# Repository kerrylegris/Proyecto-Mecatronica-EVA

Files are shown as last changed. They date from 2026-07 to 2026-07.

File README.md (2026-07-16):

# Proyecto-Mecatronica 4250-EVA
evacad
EVAFinal

## Integrantes
* Agustín Ketterer
* Isabella Silva
* Katalyna Tapia
* Joaquín Zúñiga
## Profesor
* Harold Valenzuela
## Auxiliar
* Fernando Navarrete
## Ayudantes
* Valentina Abarca
* Emilia Gutiérrez
# Índice de contenidos
* [Descripción](#descripción)
* [Objetivos](#objetivos)
* [Listado de materiales](#listado-de-materiales)
* [Diseño](#diseño)
* [Electrónica](#electrónica)
* [Software y lógica](#software-y-lógica)
* [Archivos CAD](./EVA%20CADs/)
* [Multimedia](./Multimedia)
  
# Descripción
El presente repositorio contiene la documentación, códigos y modelos 3D correspondientes al desarrollo del Robot Autobalancín "EVA".

El prototipo consiste en un péndulo invertido sobre dos ruedas capaz de mantener su verticalidad de forma autónoma frente a perturbaciones. A diferencia de los modelos clásicos, este proyecto destaca por incorporar un diseño estético basado en el personaje EVA de la película WALL-E, que responde a la solicitud de aplicar una estética futurista a nuestra propuesta, modelado íntegramente en Fusion 360. Para compatibilizar esta geometría con las exigencias dinámicas del equilibrio, se desarrolló una arquitectura interna estructurada en niveles que optimiza el centro de masa y permite un enrutamiento limpio del hardware.

A nivel de sistema, el robot es contorlado por una placa Arduino Uno, la cual procesa en tiempo real los datos de inclinación y aceleración capturados por un sensor inercial MPU-6050. Mediante la ejecución de un algoritmo de control PID ajustado experimentalmente, el microcontrolador gestiona la respuesta de los actuadores (motores DC), demostrando la aplicación práctica de principios de dinámica de cuerpos rígidos y sistemas de control en lazo cerrado.

Características principales:

* Modelado CAD: Diseño en Fusion 360 de la carcasa externa y el chasis interno por niveles.

* Fabricación: Combinación de impresión 3D (PLA) para la estética y corte láser (acrílico) para el chasis estructural.

* Electrónica: Integración de Arduino Uno, sensor MPU-6050, drivers de potencia y motores reductores.

* Control: Sistema de auto-balanceo mediante algoritmo PID en C++.
# Objetivos 
El objetivo principal de este proyecto es el diseño mecatrónico y la construcción de un robot autobalancín funcional inspirado en la estética de EVA (WALL-E). Lo central del desafío consiste en implementar un controlador PID capaz de mantener el equilibrio dinámico del sistema, compensando la inercia generada por la masa superior de su estructura.

Para lograr este objetivo, se integrarán componentes electrónicos esenciales utilizando un microcontrolador Arduino UNO como unidad central de procesamiento. Este gestionará la lógica de control programada en C++ y la lectura continua de datos del sensor inercial MPU-6050 (encargado de medir los ángulos de inclinación) para comandar los actuadores (motores DC acoplados a las ruedas). Además, el proyecto incluye el diseño de una estética original y atractiva, estructurando el modelo CAD en niveles internos para lograr la geometría fluida del personaje sin comprometer la viabilidad mecánica del péndulo invertido.

Es importante definir que el alcance del proyecto se centra en la integración exitosa del hardware y en la demostración de un sistema de autobalanceo. Por lo tanto, aunque el prototipo físico deba lidiar con las complejidades de un centro de masa elevado debido a su diseño asimétrico, el objetivo principal radica en la aplicación práctica de la teoría de control para superar este reto.

# Listado de materiales
## Hardware
### Estructura
| Componente | Cant. | Material | Proceso | Archivo asociado |
| :--- | :---: | :---: | :---: | ---: |
| Cabeza EVA |1| PETG y PLA | Impresión 3D | Cabeza EVA, parte trasera y delantera |
| Carcasa EVA |1| PETG | Impresión 3D | Carcasas |
| Placas |3| Acrílico | Corte láser | Placa base, media y superior |
| Barras estructurales |8| PLA | Impresión 3D | Barras 40mm y 50mm|
| Ruedas |2| Plástico | - | - |
| Pernos | 8 | Acero comercial | - | |-|
### Componentes electrónicos
| Componente | Cant. | Uso | 
| :--- | :---: | ---: |
| Placa Arduino UNO R3|1| Unidad lógica |
| Sensor MPU-6050 |1 | Medición de ángulo | 
| Driver L298N | 2 | Controlador de los motores |
| Motor 6V | 2 | Actuadores para el movimiento del robot |
| Batería 3,7 V | 2 | Sistema de alimentación del sistema |
| Cables de conexión | 10 | Conexión de los componentes electrónicos |

# Diseño
## Inspiración
Para cumplir con el requerimiento del proyecto de implementar una estética futurista, el diseño exterior del robot toma como inspiración directa al personaje EVA (Extraterrestrial Vegetation Evaluator) de la película de animación WALL-E.

La justificación de esta elección geométrica y visual para representar el "futuro" se sostiene en los siguientes puntos:

Minimalismo de Alta Tecnología: La ciencia ficción y el diseño industrial moderno asocian el futurismo con la limpieza visual. EVA carece de uniones visibles, engranajes expuestos o bordes afilados. Su geometría está basada en curvas continuas, superficies lisas y un contraste marcado entre el blanco puro y la pantalla negra de su rostro, emulando la sofisticación de los dispositivos tecnológicos.

El Movimiento: El concepto original de EVA es el de una sonda que levita o flota suavemente. Aunque el prototipo mecatrónico utiliza ruedas, la dinámica misma de un robot autobalancín —que constantemente ajusta su centro de masa para mantenerse erguido sobre un solo eje— genera un movimiento fluido que imita conceptualmente la sensación de "flotabilidad" o anti-gravedad, alineándose a la perfección con la percepción de un vehículo futurista.

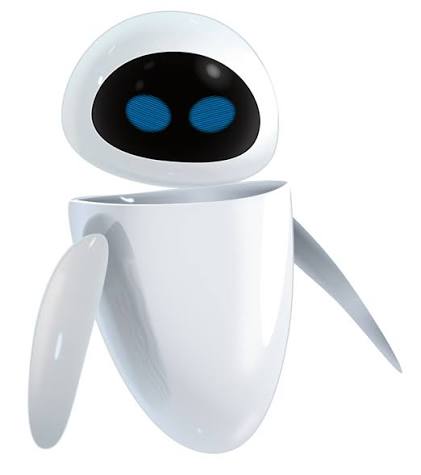
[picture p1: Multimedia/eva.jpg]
Inspiración: Personaje EVA


## Iteraciones
El desarrollo físico del robot fue un proceso iterativo, motivado por la necesidad de conciliar la compleja geometría de EVA con los estrictos requerimientos dinámicos y de distribución de masa de un péndulo invertido.
Iteración 1: Diseño preliminar con placa vertical
El enfoque: El primer diseño computacional en Fusion 360 buscó integrar la carcasa estética de EVA con una única placa vertical dispuesta en el interior, la cual serviría como soporte central para ensamblar todos los componentes electrónicos y mecánicos.
El problema: Al evaluar este ensamble preliminar, se evidenció que la placa vertical concentraba el peso de manera subóptima y limitaba severamente la flexibilidad para distribuir la masa. Además, dificultaba la accesibilidad para el cableado y el ajuste de los componentes, comprometiendo la viabilidad del balanceo.
##Diseño final 
Iteración 2: Transición al chasis horizontal por niveles
La solución: Se descartó la placa vertical en favor de un chasis interno estructurado en pisos horizontales (mediante placas de acrílico cortadas en láser y separadores cilíndricos).
El impacto: Esta nueva arquitectura permitió independizar el sistema estructural de la carcasa externa. Al tener niveles, se logró bajar drásticamente el centro de gravedad ubicando la batería y los motores en la base, lo cual fue fundamental para compensar la alta inercia generada por el apéndice superior impreso en 3D (la cabeza de EVA).

# Electrónica

El hardware de este robot autobalancín está compuesto por un microcontrolador central que procesa la información sensorial y comanda los actuadores en cuestión de milisegundos. La arquitectura electrónica se divide en los siguientes componentes principales:

*   **Microcontrolador (Arduino):** Ejecuta el lazo de control PID a alta velocidad y coordina la comunicación continua entre los sensores y el actuador.
*   **Módulo MPU6050 (Giroscopio y Acelerómetro):** Es el encargado de medir la inclinación física del cuerpo completo del robot en el espacio. Es el sensor principal que proporciona la retroalimentación del ángulo real.
*   **Driver de Motores L298N:** Actúa como puente de potencia; recibe las señales lógicas de dirección y los pulsos de velocidad (PWM) desde el microcontrolador, y las transforma en la corriente eléctrica necesaria para mover ambos motores.
*   **Motores DC:** Proporcionan el torque necesario para desplazar la base de la estructura e intentar devolver el centro de masa a su punto de equilibrio vertical.

**Distribución de Energía**
Debido a la alta demanda de corriente que exigen los motores al cambiar de dirección abruptamente para equilibrar la estructura, el circuito requiere una fuente de alimentación externa con buena capacidad de descarga, conectada directamente al módulo L298N. 

<!-- A continuación, se presenta el esquema detallado de las conexiones del sistema:y -->

# Software y lógica
El bloque de texto que contiene el código con el que se programó el PID se puede encontrar en su respectiva [carpeta](./Código). 

El propósito de este proyecto es lograr que el robot mantenga el equilibrio en dos ruedas de forma autónoma, pero debido a naturaleza inestable tenderá a caer hacia adelante o hacia atrás. Para contrarrestar la gravedad se utiliza un sistema de control de lazo cerrado que calcula constantemente su ángulo de inclinación y acelera sus ruedas en la misma dirección de la caída, empujando la base debajo del centro de masa para regresar a su punto de equilibrio (0 grados). La siguiente imagen corresponde al diagrama del sistema de control que muestra el flujo de las señales, más adelante se explica con mayor detalle la descripción de cada parte.

Diagrama eva (1)

El código está diseñado para operar en un ciclo de tiempo determinado (200 Hz o cada 5 milisegundos) y se divide en tres pilares fundamentales:

**1. Calibración y lectura sensorial**
Al encender, el sistema ejecuta una fase de calibración de 3 segundos. Durante este tiempo, promedia los valores en reposo del sensor MPU6050 para establecer un "cero" real, compensando cualquier error de fábrica. 
Durante el ciclo continuo, el sistema calcula el ángulo de inclinación actual  (`input_angle`), fusionando los datos del acelerómetro y el giroscopio mediante un filtro complementario. Este filtro se configura para un 98% en las lecturas del giroscopio y en un 2% en el acelerómetro, para corregir el error acumulado que sufre el giroscopio a largo plazo.

**2. Controlador PID**
El error entre el ángulo objetivo y el real alimenta la ecuación de control PID, que calcula la fuerza necesaria (`output_u`) para enderezar el robot:
*   **Proporcional (Kp):** La fuerza principal;  cuanto más se inclina el robot, más potencia exige.
*   **Integral (Ki):** Acumula errores pasados para corregir pequeñas desviaciones. Incluye un límite (*anti-windup*) para evitar que la memoria se sature si el sistema no logra estabilizarse inmediatamente.
*   **Derivador (Kd):** Reacciona a la velocidad de la caída; frena la potencia si el robot ya está regresando rápidamente a su centro, evitando que oscile de un lado a otro.

**3. Accionamiento de Motores y Seguridad**
El código compensa la fricción sumando un pulso mínimo (`MIN_PWM = 30`), asegurando que los motores reaccionen instantáneamente ante cualquier corrección, por muy pequeña que sea. 
Adicionalmente, se incluye un mecanismo de seguridad pasivo: si el ángulo supera los 60 grados de inclinación (`ANGULO_CORTE`), el sistema asume que la estructura ya cayó. Para evitar daños o movimientos erráticos por el suelo se corta la potencia y se reinicia la memoria del controlador.

A continuación se puede observar el diagrama de lógica que sigue la programación de EVA.
<details>
<summary>Ver Diagrama de lógica</summary>
  
```mermaid
graph TD
    %% Fase de Inicialización
    A([Inicio de Sistema]) --> B[Configurar Serial e I2C]
    B --> C[inicializarMOTORS]
    C --> D[inicializarSENSORS]
    D --> E{¿Pasaron 3 seg?}
    E -- No --> F[Leer y acumular datos MPU]
    F --> E
    E -- Sí --> G[Calcular offsets]
    G --> H[Guardar prev_time]

    %% Bucle Principal y Peaje de Tiempo
    H --> I([Inicio Loop])
    I --> J[Calcular dt]
    J --> K{¿dt >= 0.005s?}
    K -- No --> I
    K -- Sí --> L[leerSENSORS y calcular input_angle]
    
    %% Secuencia de Control
    L --> M{¿Ángulo > 60°?}
    M -- Sí --> N[output_u = 0 y borrar memorias]
    N --> P[controlarMOTORS]
    
    M -- No --> O[calcularPID para obtener output_u]
    O --> P
    
    P --> Q[imprimirPLOTTER]
    Q --> R[Actualizar prev_time]
    R --> I
```
</details>

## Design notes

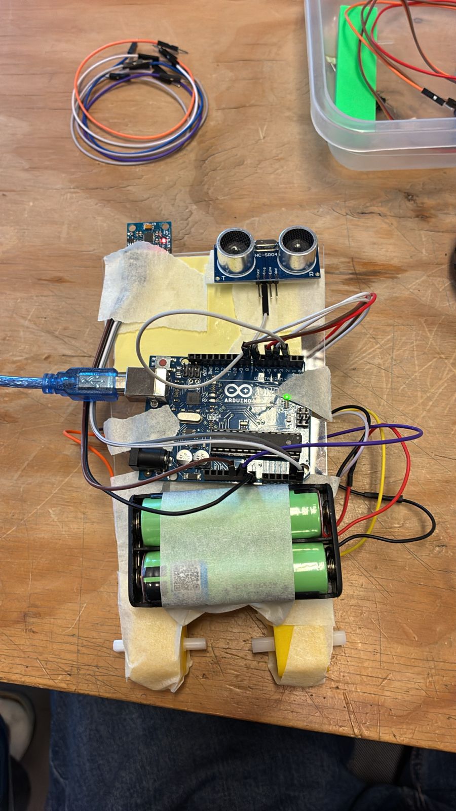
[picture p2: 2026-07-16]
Multimedia/evintestinos3.jpeg

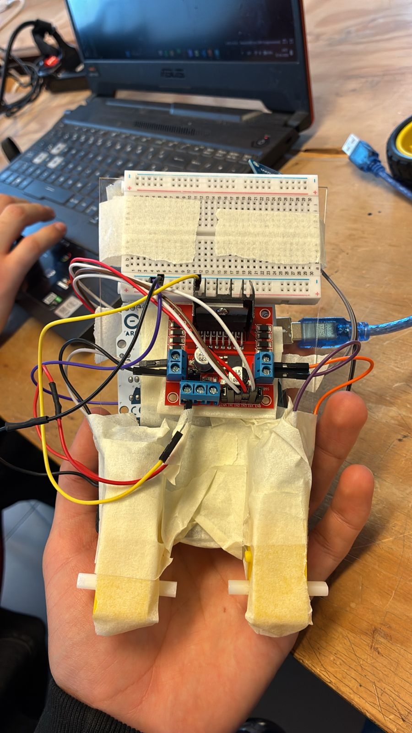
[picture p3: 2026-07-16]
Multimedia/evintestinos2.jpeg

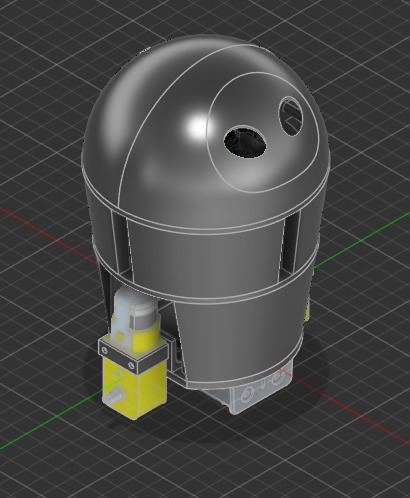
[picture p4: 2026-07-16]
Multimedia/evacad.jpeg

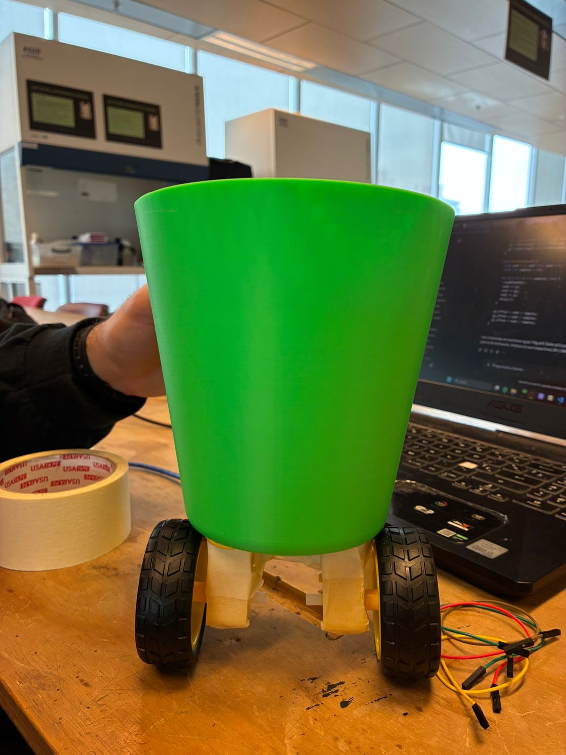
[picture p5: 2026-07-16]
Multimedia/evarcasa.jpeg

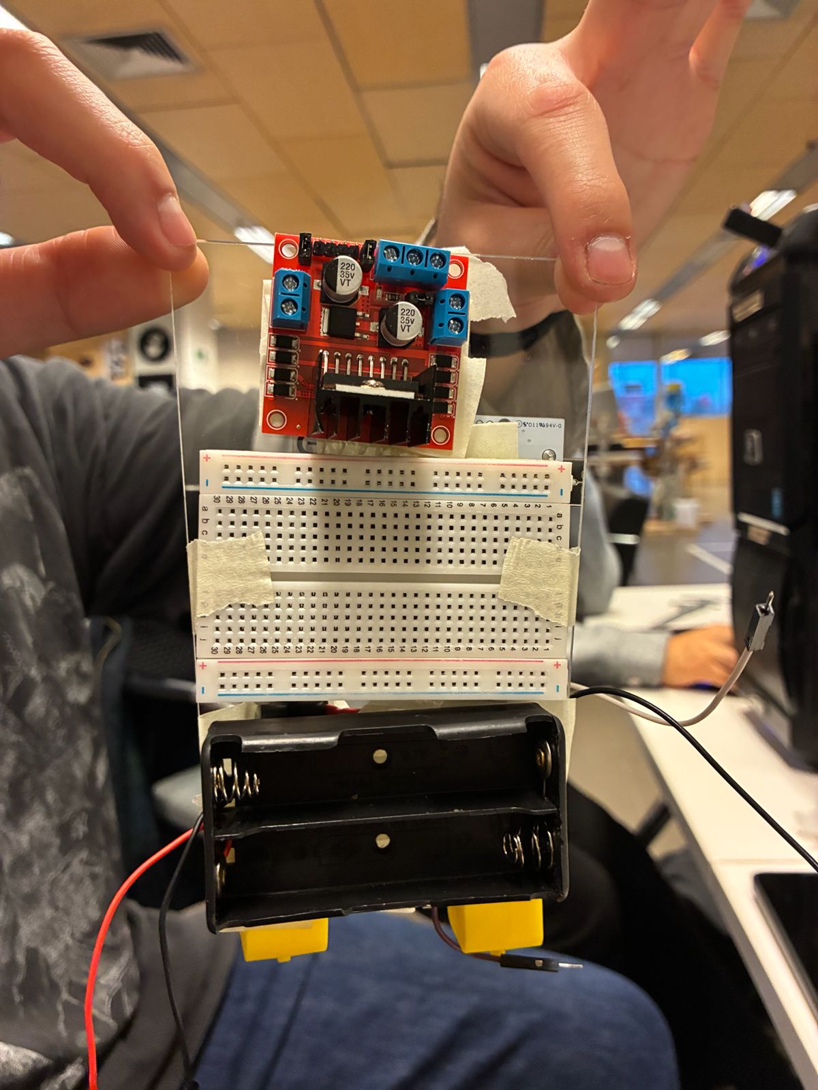
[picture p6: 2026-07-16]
Multimedia/eva00.jpeg

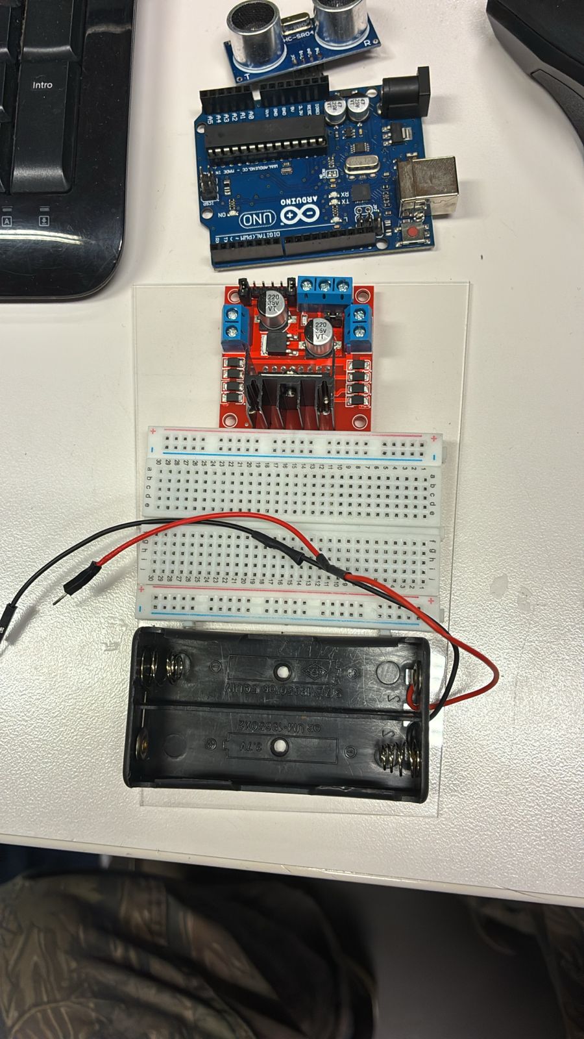
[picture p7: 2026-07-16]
Multimedia/eva0.jpeg

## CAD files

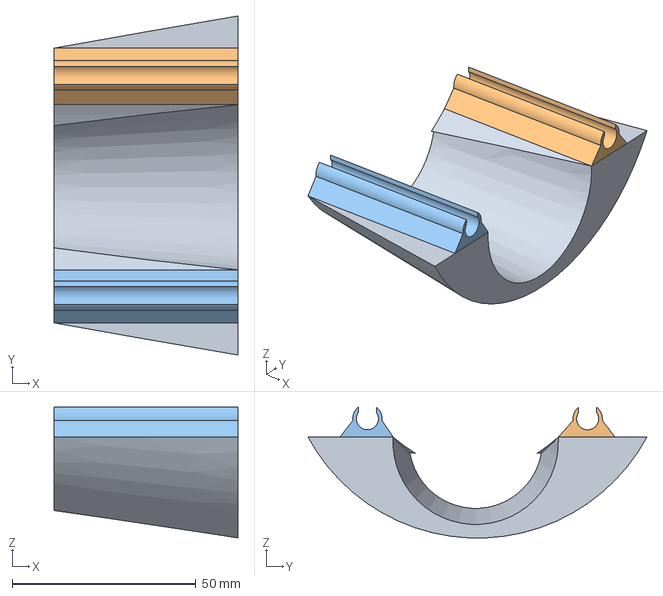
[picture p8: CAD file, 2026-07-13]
EVA CADs/carcasa abajo.step
50.0 x 92.3 x 35.6 mm

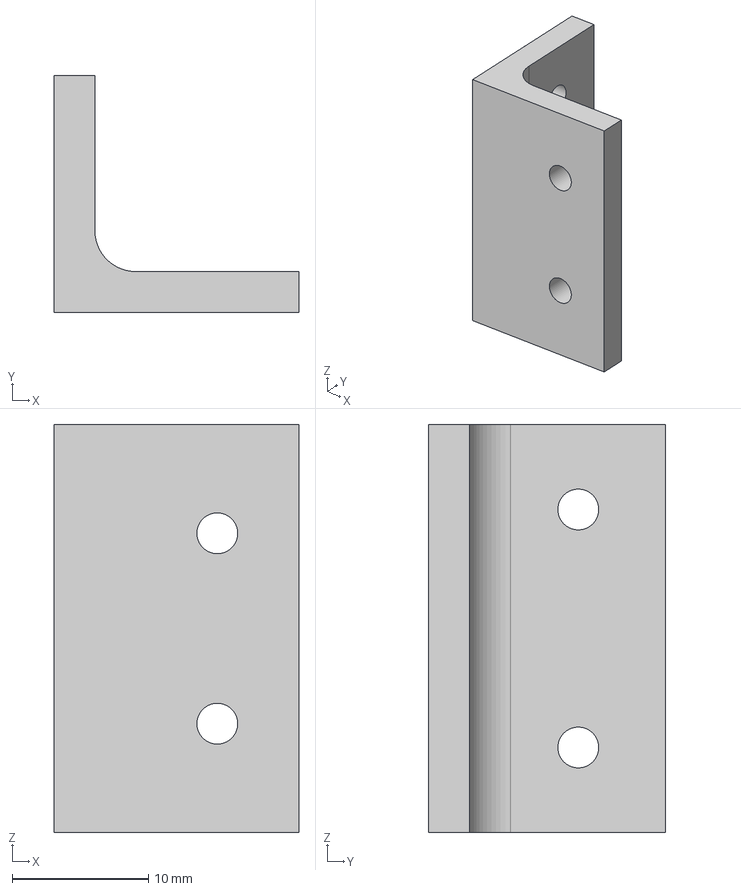
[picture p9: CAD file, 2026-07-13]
EVA CADs/soporte motores.step
18.0 x 17.4 x 30.0 mm

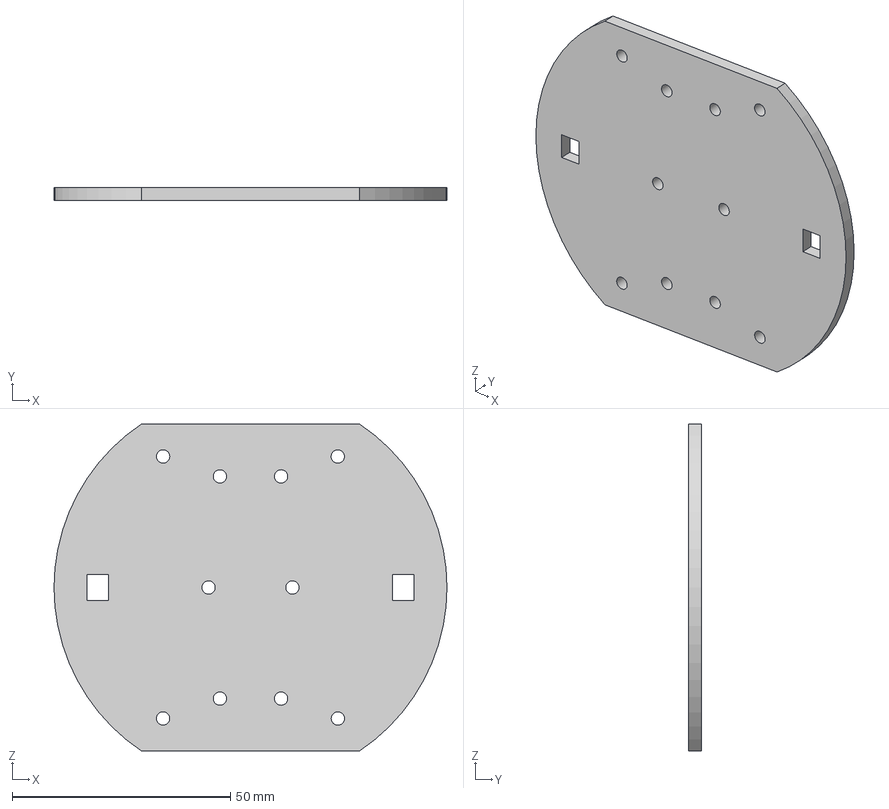
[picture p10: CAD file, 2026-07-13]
EVA CADs/placa base.step
90.0 x 3.00 x 74.9 mm

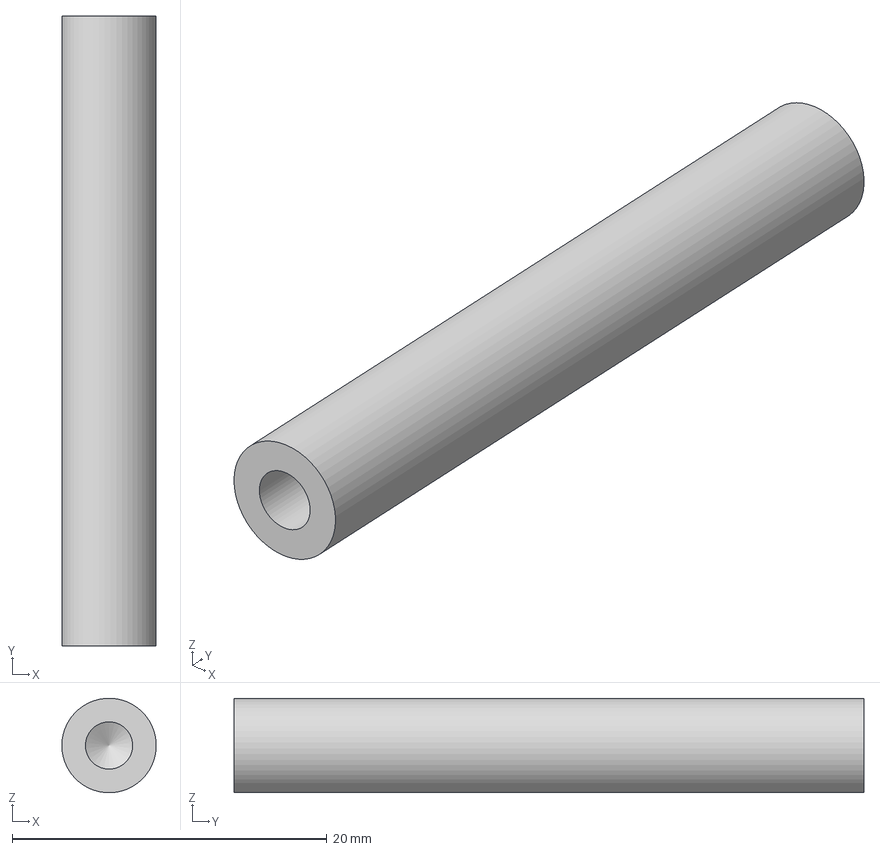
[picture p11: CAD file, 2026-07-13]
EVA CADs/barras 40mm.step
5.99 x 40.0 x 6.00 mm

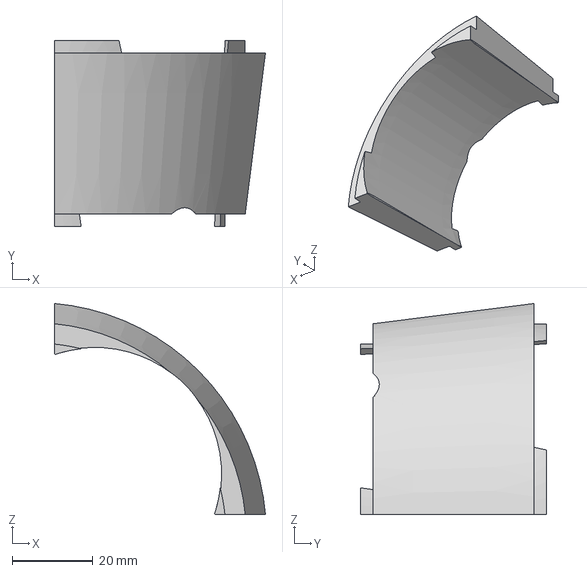
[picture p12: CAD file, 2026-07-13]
EVA CADs/carcasas medias.step
52.3 x 46.0 x 52.3 mm

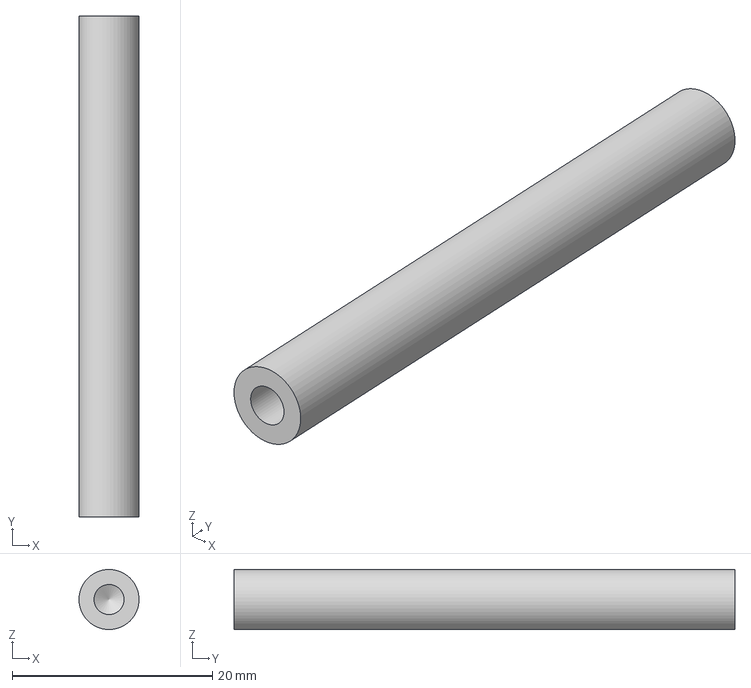
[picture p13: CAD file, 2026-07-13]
EVA CADs/barras 50mm.step
5.99 x 50.0 x 6.00 mm

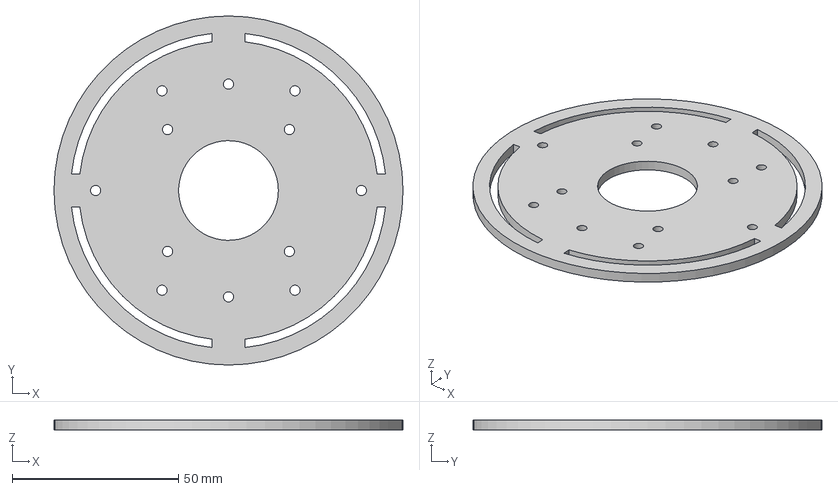
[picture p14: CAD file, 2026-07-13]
EVA CADs/placa media.step
105.0 x 105.0 x 3.00 mm

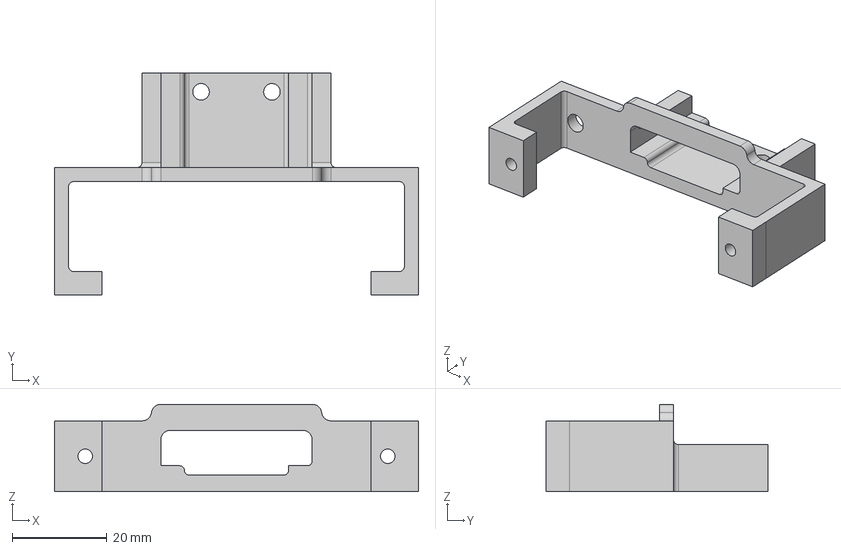
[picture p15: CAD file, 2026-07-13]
EVA CADs/soporte sensor.step
77.0 x 47.0 x 18.5 mm

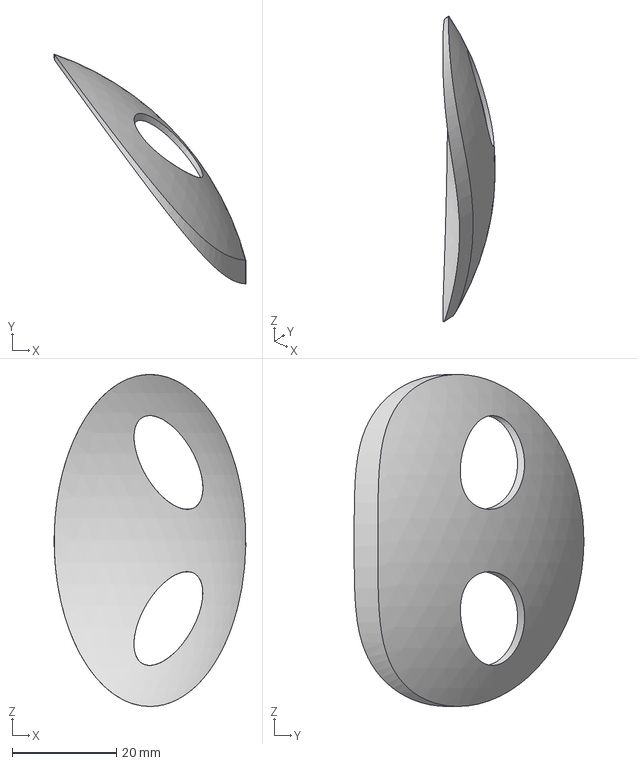
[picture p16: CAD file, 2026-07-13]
EVA CADs/cara.step
36.8 x 44.2 x 63.8 mm

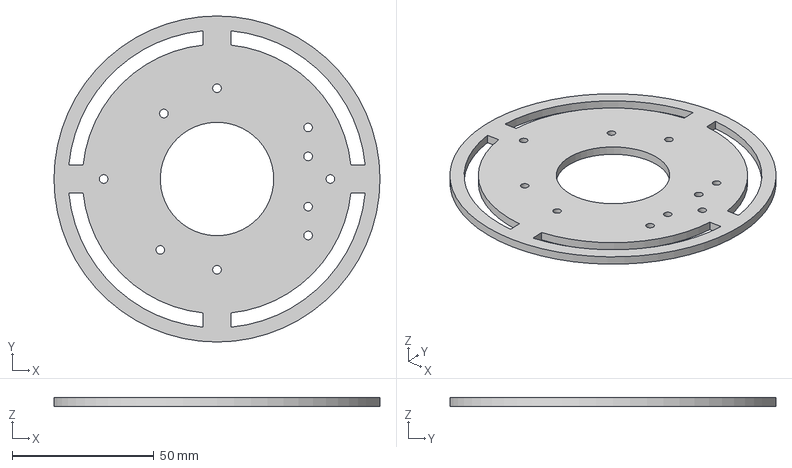
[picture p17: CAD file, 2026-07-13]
EVA CADs/placa superior.step
115.0 x 115.0 x 3.00 mm

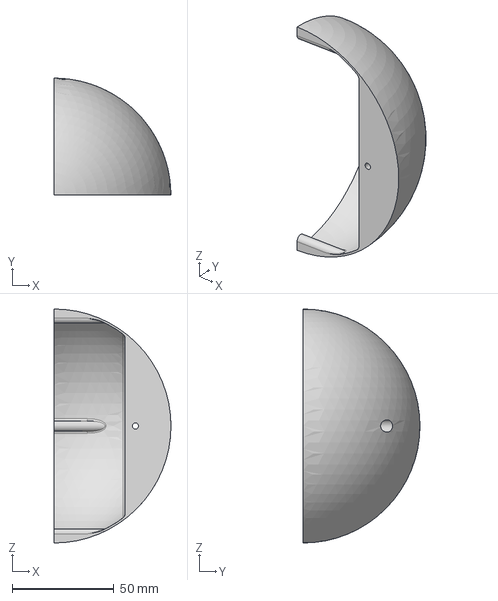
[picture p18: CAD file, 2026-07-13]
EVA CADs/cabeza parte de atrás.step
57.5 x 57.5 x 115.0 mm

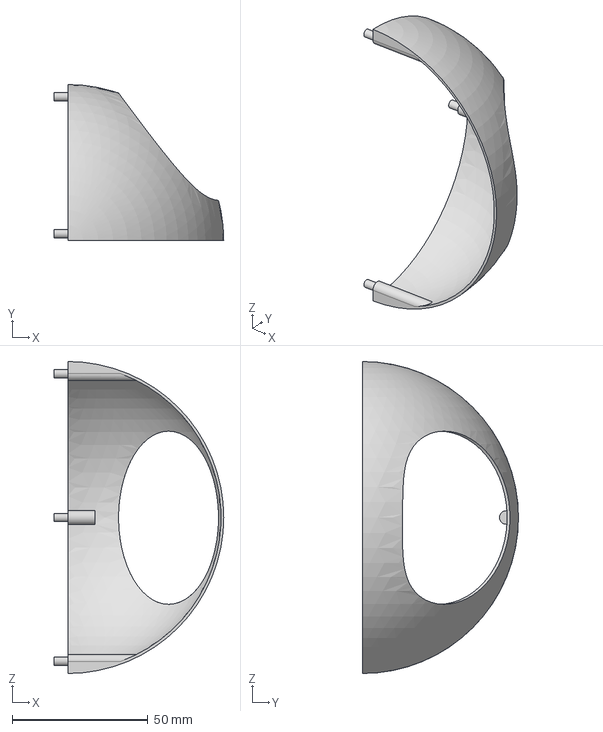
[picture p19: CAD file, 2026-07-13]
EVA CADs/cabeza parte delantera.step
62.5 x 57.5 x 115.0 mm

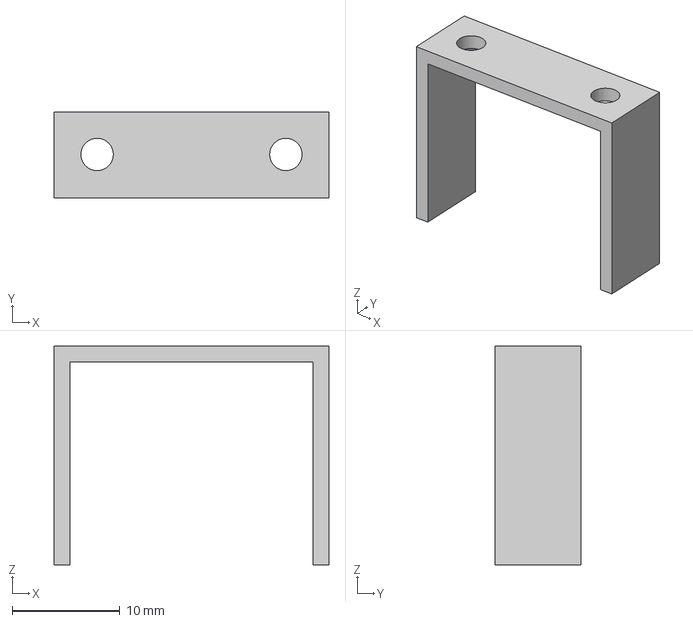
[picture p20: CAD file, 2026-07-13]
EVA CADs/protege motores.step
25.5 x 8.00 x 20.3 mm

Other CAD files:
EVA CADs/barras 40mm.f3d
EVA CADs/barras 50mm.f3d
EVA CADs/cabeza parte de atrás.f3d
EVA CADs/cabeza parte delantera.f3d
EVA CADs/cara.f3d
EVA CADs/carcasa abajo.f3d
EVA CADs/carcasas medias.f3d
EVA CADs/placa base.f3d
EVA CADs/placa media.f3d
EVA CADs/placa superior.f3d
EVA CADs/protege motores.f3d
EVA CADs/soporte motores.f3d
EVA CADs/soporte sensor.f3d

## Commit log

2026-07-16 Rename código to código pid
2026-07-16 Rename código pid to Código/código pid
